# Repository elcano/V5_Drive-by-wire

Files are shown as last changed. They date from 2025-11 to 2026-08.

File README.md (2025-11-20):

# V5_Drive-by-wire
Updated code and PCB for light vehicle drive by wire.

This repository is for use with the **Drive by Wire** board created to be used for the ELCANO self-driving tricycle. It controls throttle (Ebike controller), brakes (solenoid) and steering (either linear servo or motor controller board with a linear actuator). All vehicle actions are logged to an SD card, which is the main data for debugging. Vehicle can be controlled by

1) 6-channel Radio Control (RC) unit

2) Operator controls (OP)

3) Vehicle automation computer via CAN. We have demonstrated a Jetson Nano using a Pixhawk to find GNSS points and move from waypoint to waypoint.

In order for this module to run external libraries are required.

Libraries needed are listed below:

Version 4 and 5 (Arduino Due)  _______________________________________________
* Due CAN and CAN Common by Collin Kidder
    https://github.com/collin80/due_can
    https://github.com/collin80/can_common

## To Install

* Download the **Drive_By_Wire** module into the project parent directory
```
git clone https://github.com/elcano/Drive-by-wire.git
```
* Move into the **Drive_By_Wire** folder
```
cd Drive_By_Wire
```
* Download the required libraries
```
git clone https://github.com/SweBarre/MCP48x2.git
git clone https://github.com/ivanseidel/DueTimer.git
git clone https://github.com/collin80/can_common.git
git clone https://github.com/collin80/due_can.git
```
* Add the folders above to the IDE directory. In Windows, add the required libraries to: C:\Users\<username>\Documents\Arduino\libraries
* Arduino Due requires additional installation. On the IDE, go to Tools -> Boards -> Boards Manager -> Arduino SAM Boards (32-bits ARM Cortex-M3) 

## Navigating Arduino IDE: 
* **Selecting Board:** Tools -> Board -> Arduino SAM Boards -> Arduino Due
* **Selecting Serial Port:** Tools -> Port -> COM (Arduino Due)
* **Accessing Serial Monitor:** Right-hand Corner -> Select Baud Rate (115200)

## Drive-by-Wire: 
* **Low-level board code with RC control support with existing code for brakes, steering, and throttle.**

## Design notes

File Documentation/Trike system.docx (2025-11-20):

# Trike system

High level organization is given in the block diagram

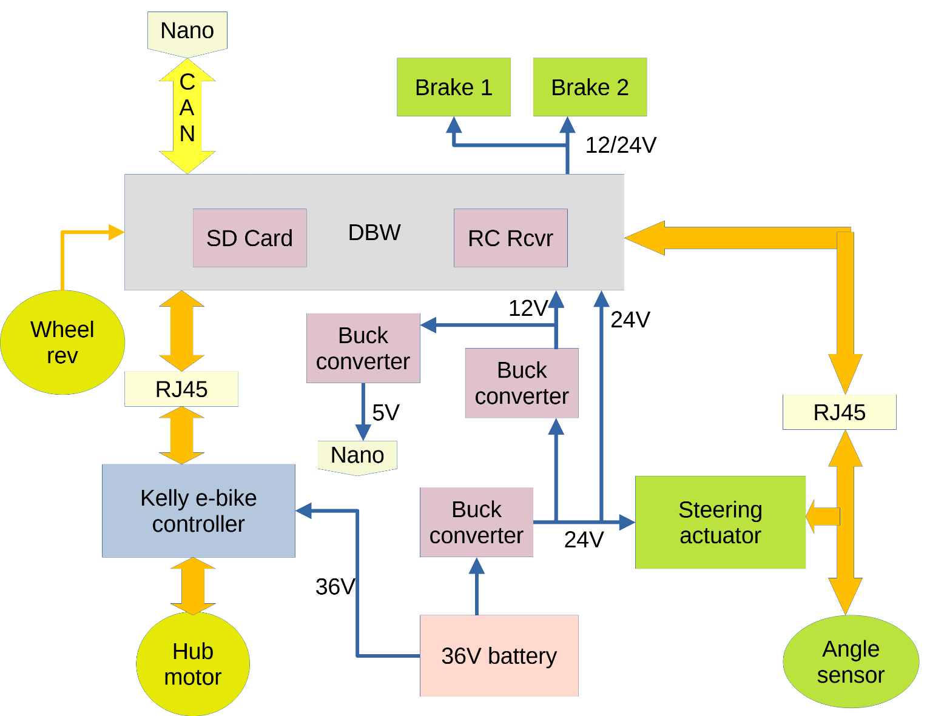
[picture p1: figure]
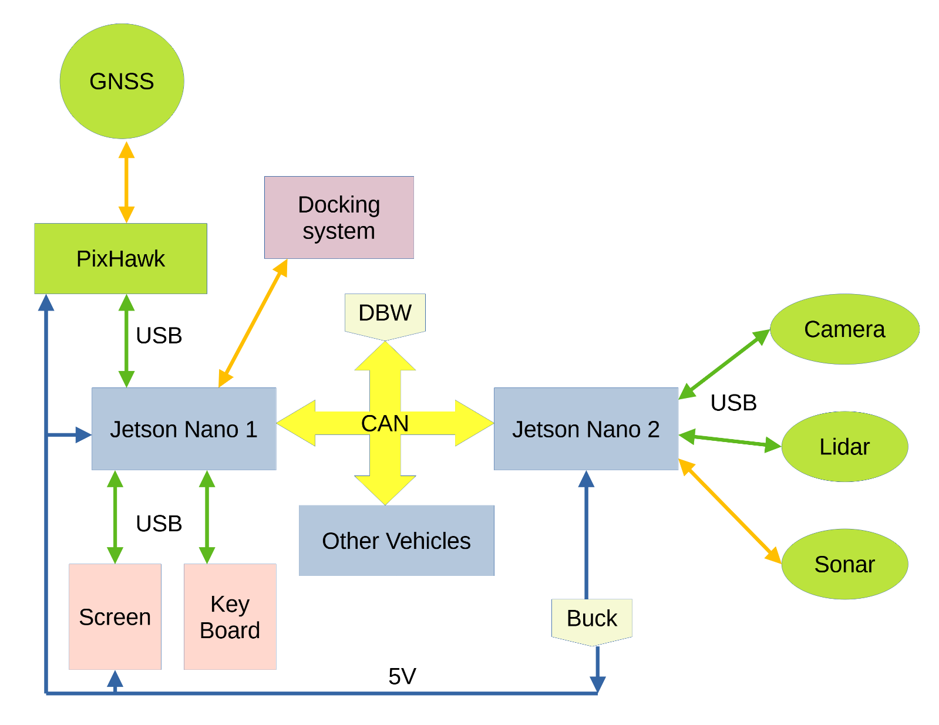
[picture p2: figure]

The steering system can be either a linear servo or a linear actuator with H-bridge. The present H-bridge system is not reliable, so the current version uses the servo. An angle sensor gives feedback on the wheel angle. The analog signal is subject to noise; it may be supplemented by a digital sensor. The servo can run on 12-24V. We use the 24V, supply, but it could also take 12V. The DBW board has a power outlet to the actuator for delaying its turn on. This signal should be jumpered to take either 12 or 24V.

Signals to the actuator and sensor are:

| Steering end | | DBW End
RJ45 Pin | V5A | V5B | V5A Pin (DUE) | V5B Pin (DUE)
1 | L_ANG | MISO | (A10) - in | MISO - in
2 | L_RTN | ANG CS | (A10) - in | D39 - out
3 | R_ANG | SCK | (A11) - in | SCK - in
4 | R_RTN | MOSI | (A11) – in | MOSI - out
5 | GND | GND | NC | NC
6 | PWM | R_TURN | D48 - out | D48 - out
7 | NC | L_TURN | D41 - out | D41 - out
8 | 5V | 5V | NC | NC

Ground and 5V for the angle sensors comes from the steering servo, not the Arduino. Signals in parenthesis require additional processing before going to the Due. The angle sensor pins subtract out the return signal. Throttle signals must be converted between 3.3 and 5 volts. Throttle control is handled by the Kelly e-bike controller. It must receive the 36V signal from the switch to turn on the controller. Its signals are:

RJ45 Pin | Signal | Due Pin | Kelly pin | Kelly wire color
1 | REV/FWD | (D36) | M12 | White
2 | Current meter | (A9) | F8 | Dark blue
3 | Brake | (DAC 1) | F2 | White
4 | BRK_SW (Regen) | (D43) | F13 | Brown
5 | Spare | (D24)
6 | Throttle | (DAC 0) | F3 | Dark green
7 | Speedometer | (D22) | 17 Hall B | Green
8 | EBIKE alive | (D45) | F4 or M11 | Purple or Dark grey
| 36V | | M7 | Pink

Speed is computed from a reed switch that produces an interrupt once per wheel revolution. A more accurate speed could be obtained from the Hall Phase signal with several pulses per revolution. This system has not been implemented. A third possibility would be a sensor on the axle that measures shaft rotation speed.

The trike can operate as a remote-control vehicle, via the RC unit. It can operate autonomously from a command from the Jetson Nano giving the speed and steering angle to reach the next waypoint. For computing paths, turn radius may be easier to implement than using wheel angle directly. A path segment can be specified by the reciprocal of the turning angle and the distance to travel on the segment. Going straight has an infinite turn angle; the reciprocal is 0. The Jetson Nano will need to take the route between waypoints and convert it into straight segments and circular arcs. The DBW software will have the task of setting the wheel angle to match a desired turn radius.

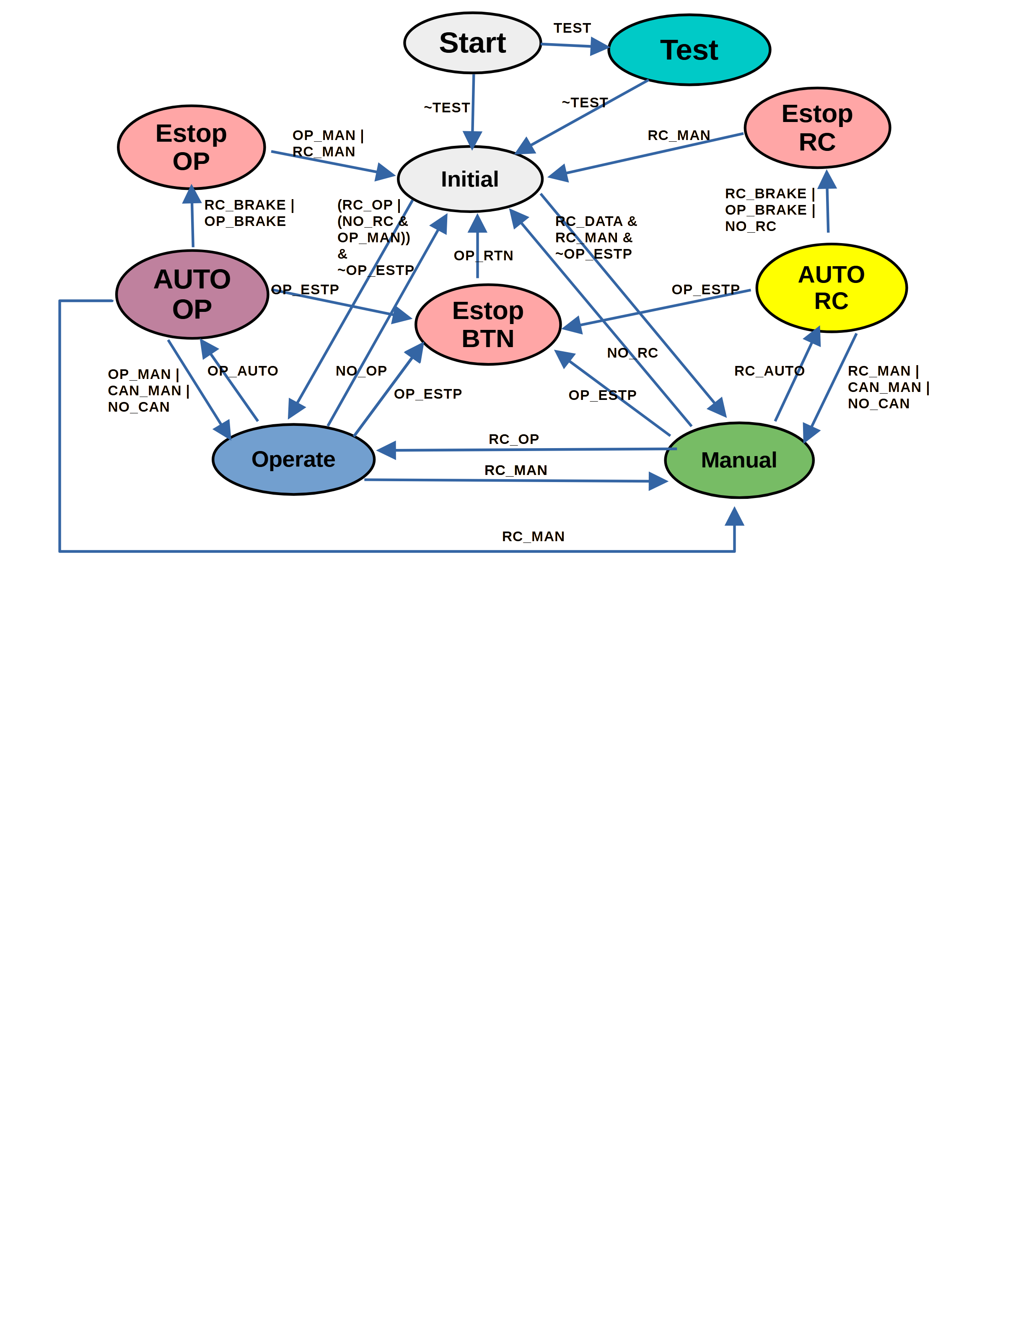
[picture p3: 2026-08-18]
Documentation/State transitions3.png

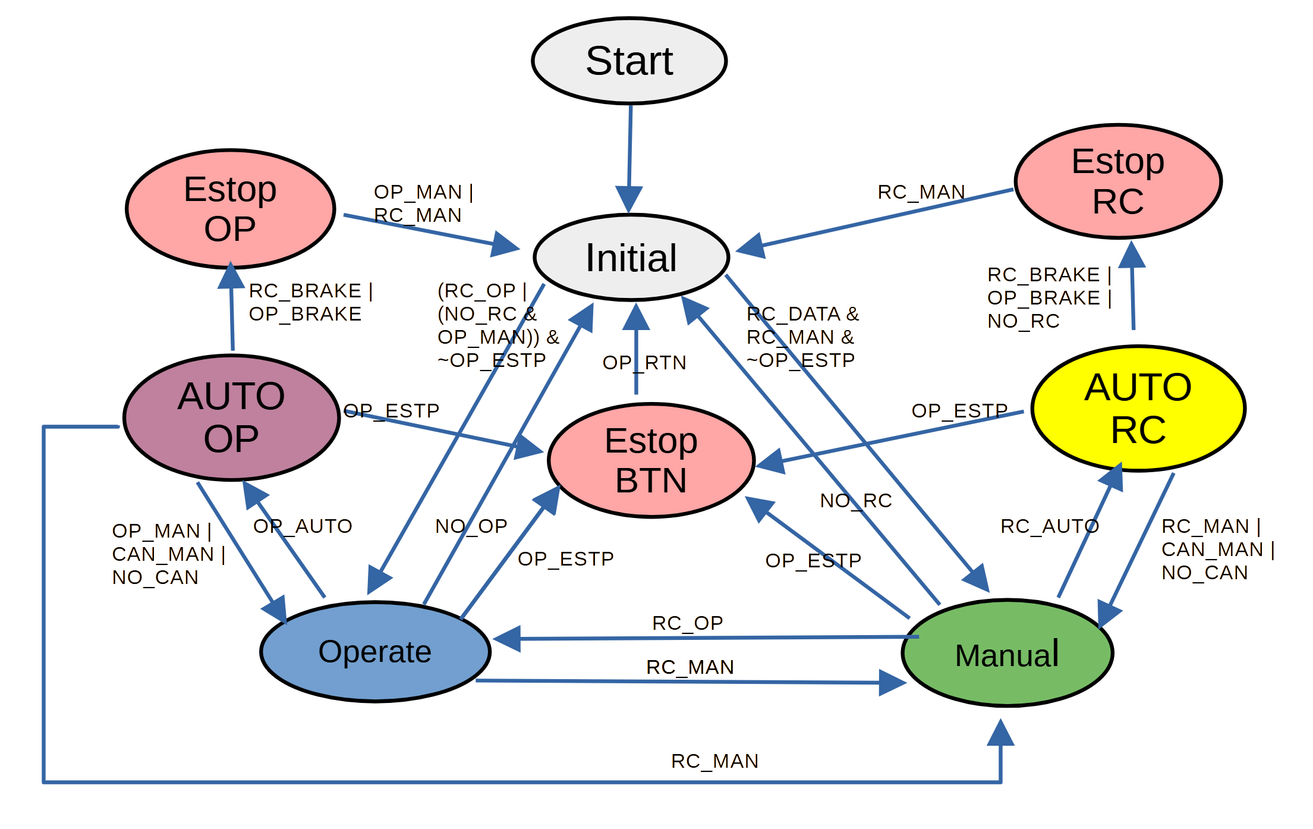
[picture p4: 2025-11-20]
Documentation/State transitions.png

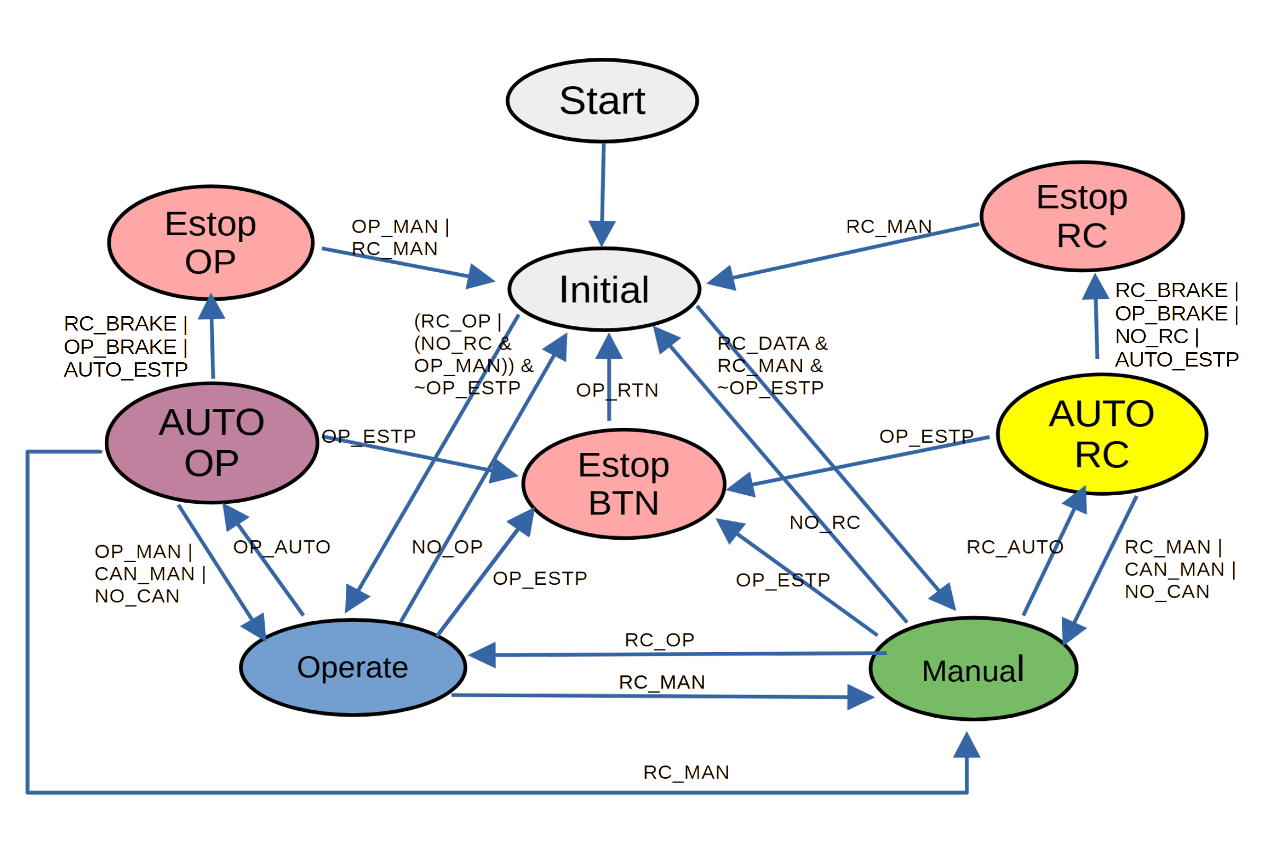
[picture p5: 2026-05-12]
Documentation/State transitions2.png

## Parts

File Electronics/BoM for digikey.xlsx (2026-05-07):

 |  |  |  |  |  |  |  | Components need to buy
Qty | unit price | board price | 10 board | On Hand | Need | Total | Device Name | Value | Notes | Digikey Part Number | Package | Part Label | Description | DESCRIPTION | External Link
1 | 0.1 | 0.1 | $1.00 | 0 | 10 | $1.00 | Capcitors | 47uF |  | 732-8823-1-ND | 5x125 mm case 2mm pitch | C16 | Aluminum Electrolytic Capacitors | 47 µF 25 V Aluminum Electrolytic Capacitors Radial, Can 2000 Hrs @ 105°C | https://www.digikey.com/en/products/detail/w%C3%BCrth-elektronik/860020472006/5727060
~~1~~ | ~~0.118~~ | ~~0.118~~ | ~~$1.18~~ | ~~0~~ | 0 | $0.00 | ~~Capcitors~~ | ~~47uF~~ | 0 in stock | ~~399-ESS476M025AE2EACT-ND~~ | ~~5x7 mm case 2mm pitch~~ | ~~C16~~ | ~~Aluminum Electrolytic Capacitors~~ | ~~47 µF 25 V Aluminum Electrolytic Capacitors Radial, Can 1000 Hrs @ 105°C~~ | ~~https://www.digikey.com/en/products/detail/kemet/ess476m025ae2ea/13176268~~
3 | 0.055 | 0.165 | $1.65 | 0 | 30 | $1.65 | Diode |  |  | 1N4148FSCT-ND | Cut Tape (CT) | D11,D12,D13 | DIODE STANDARD 100V 200MA DO35 | Diode 100 V 200mA Through Hole DO-35 | https://www.digikey.com/en/products/detail/onsemi/1N4148TR/458811?s=N4IgTCBcDaIIwDkAsckA4BiBlAwgFQFoEAREAXQF8g
3 | 0.088 | 0.264 | $2.64 | 0 | 30 | $2.64 | 2N3904 BJT |  |  | 4878-2N3904CT-ND |  | Q1,Q2,Q3 | BJT | Bipolar (BJT) Transistor NPN 40 V 200 mA 300MHz 625 mW Through Hole TO-92 | https://www.digikey.com/en/products/detail/diotec-semiconductor/2N3904/13164701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
2 | 0.23 | 0.46 | $4.60 | 0 | 20 | $4.60 | Test Points |  |  | 36-1033-ND |  | DAC0,GND1 | PC TEST POINT LOOP | PC Test Point, Loop Brass Tin Plating Through Hole Mounting Type | https://www.digikey.com/en/products/detail/keystone-electronics/1033/315149
1 | 0.214 | 0.214 | $2.14 | 0 | 10 | $2.14 | Switch |  |  | CKN9092-ND |  | SW1 | SWITCH TACTILE SPST-NO 0.05A 12V | Tactile Switch SPST-NO Top Actuated Through Hole | https://www.digikey.com/en/products/detail/c-k/PTS645SL50-2-LFS/1146781?s=N4IgTCBcDaIMIGkByBOADCsBaJAREAugL5A
1 | 3.19 | 3.19 | $31.90 | 0 | 10 | $31.90 | R-78E5.0-0.5 |  |  | 945-1648-5-ND | 11.6x8.5x10.4 2.54 pitch | U6 | Voltage regulator --5V | Linear Regulator Replacement DC DC Converter 1 Output 5V 500mA 7V - 28V Input | https://www.digikey.com/en/products/detail/recom-power/R-78E5-0-0-5/2834904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
3 | 0.659 | 1.977 | $19.77 | 10 | 20 | $13.18 | RJ_45 |  |  | 609-1046-ND | 15.3x17.74x12.7 | J1,J2,J3 | Modular/Ethernet Connector (RJ45) Jack | in stock, | https://www.digikey.com/en/products/detail/amphenol-cs-fci/54602-908LF/1001360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
3 | 0.353 | 1.059 | $10.59 | 24 | 6 | $2.12 | Pinheader-1x6 |  |  | S7004-ND |  | J4,J5,J6 | Pin connector(female) |  | https://www.digikey.com/en/products/detail/sullins-connector-solutions/PPTC061LFBN-RC/810145
1 | 0.321 | 0.321 | $3.21 | 10 | 0 | $0.00 | Pinheader-1x4 |  |  | S7037-ND |  | J7 | Pin connector(female) |  | https://www.digikey.com/en/products/detail/sullins-connector-solutions/PPPC041LFBN-RC/810176
1 | 0.435 | 0.435 | $4.35 | 10 | 0 | $0.00 | Pinheader-1x8 |  |  | S7006-ND |  | J8 | Pin connector(female) |  | https://www.digikey.com/en/products/detail/sullins-connector-solutions/PPTC081LFBN-RC/810147
 |  |  |  |  | 200 | $5.84 | Pins for socket | 500798000 |  | WM1142CT-ND | Molex |  | CONN SOCKET 26-28AWG CRIMP TIN | Socket Contact Tin 26-28 AWG Crimp
1 | 0.197 | 0.197 | $1.97 | 0 | 10 | $1.97 | Female connector - 1x6 | 510210600 |  | WM1724-ND | Molex
2 | 0.062 | 0.124 | $1.24 | 0 | 20 | $1.24 | Female connector - 1x4 | 10155244-04111lf |  | 609-10155244-04111LF-ND | Amphenol
1 | 0.689 | 0.689 | $6.89 | 0 | 10 | $6.89 | Male pinheader - 1x6 | 532610671 |  | WM7624CT-ND | Molex | J9 | CONN HEADER SMD R/A 6POS 1.25MM | Connector Header Surface Mount, Right Angle 6 position 0.049" (1.25mm)
~~1~~ | ~~0.426~~ | ~~0.426~~ | ~~$4.26~~ | ~~0~~ | ~~0~~ | ~~$0.00~~ | ~~Male pinheader - 1x6~~ | ~~10114830-10106LF~~ |  | ~~609-6042-1-ND~~ | ~~Amphenol~~ | ~~J9~~ | ~~CONN HEADER SMD R/A 6POS 1.25MM~~ | ~~Connector Header Surface Mount, Right Angle 6 position 0.049" (1.25mm)~~
2 | 0.242 | 0.484 | $4.84 | 0 | 20 | $4.84 | Male pinheader - 1x4 | 10155242-04111LF |  | 609-10155242-04111LFCT-ND | Amphenol | J10,J11 | WF 1.25MM 90 HF LCP-10155242-041 | Connector Header Surface Mount, Right Angle 4 position 0.049" (1.25mm)
1 | 0.416 | 0.416 | $4.16 | 0 | 10 | $4.16 | JST Pinheader-1x6 | SM06B-GHS-TB |  | 455-1568-1-ND | Back order | J9 | CONN HEADER SMD R/A 6POS 1.25MM | Connector Header Surface Mount, Right Angle 6 position 0.049" (1.25mm) | https://www.digikey.com/en/products/detail/jst-sales-america-inc/SM06B-GHS-TB/807790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
2 | 0.33 | 0.66 | $6.60 | 0 | 20 | $6.60 | JST Pinheader-1x4 | SM04B-GHS-TB |  | 455-1566-1-ND | Back order | J10,J11 | CONN HEADER SMD R/A 4POS 1.25MM | Connector Header Surface Mount, Right Angle 4 position 0.049" (1.25mm) | https://www.digikey.com/en/products/detail/jst-sales-america-inc/SM04B-GHS-TB/807788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
5 | 0.49 | 2.45 | $24.50 | 5 | 0 | $0.00 | ~~Stacking Pinheader-1x8~~ |  |  | ~~HDR100IMP08F-G-V-ST~~ |  | ~~J14,J15,J16,J18,J19~~ | ~~0.1" 8 PIN VERTICAL FEMALE STACK~~ | ~~8 Position Header Connector 0.100" (2.54mm) Through Hole Gold~~
1 | 1 | 1 | $10.00 | 4 | 0 | $0.00 | ~~Stacking Pinheader-1x10~~ | ~~Include 6~~ |  | ~~920-0087-01~~ |  | ~~J17~~ | ~~CONN HDR 10POS 0.1 GLD PCB 1=6PC~~ | ~~10 Position Header Connector 0.100" (2.54mm) Through Hole Gold~~
1 | 0.49 | 0.49 | $4.90 | 0 | 0 | $0.00 | ~~Stacking Pinheader-2x18~~ | ~~Uses 2 1x8 and 2 1x10~~ |  | ~~HDR100IMP08F-G-V-ST & 920-0087-01~~ |  | ~~J20~~ | ~~using two 1x8 and two 1x10~~ | ~~The price here is for the 1x8 version. For the 1x10 version, it already includes more components, so there is no need to buy anything extra.~~
 |  |  |  | 25 |  |  | ~~Stacking pinheade 1x6~~
1 | 0.49 | 0.49 | $4.90 | 20 | 0 | $0.00 | ~~Stacking Pinheader-2x3~~ |  |  | ~~S7106-ND~~ |  | ~~J21~~ | ~~CONN HDR 6POS 0.1 GOLD PCB~~ | ~~6 Position Header Connector 0.100" (2.54mm) Through Hole Gold~~
2 | 5.95 | 11.9 | $11.90 |  | 2 | $11.90 | Stacking pinheader set | 5-1x36 |  | 3366 |  | J20,J16,J18,J19 |  |  | https://www.adafruit.com/product/3366
1 | 1.76 | 1.76 | $17.60 | 0 | 10 | $17.60 | Stacking Pinheader set | 1-2x3,2-1x6,2-1x8,1-1x10 |  | 85 |  | J21,J17,J14,J15 |  |  | https://www.adafruit.com/product/85
1 | 0.745 | 0.745 | $7.45 | 0 | 10 | $7.45 | Jack DC power |  |  | 839-54-00129-ND |  | J22 | Jack DC power supply | Power Barrel Connector Jack 2.10mm ID (0.083"), 5.50mm OD (0.217") Through Hole, Right Angle | https://www.digikey.com/en/products/detail/tensility-international-corp/54-00129/9685438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
4 | 0.12 | 0.48 | $4.80 | 40 | 0 | $0.00 | Jumper pins |  |  | 732-5316-ND |  | JP5,JP6,JP7,JP8 | Jumpers using Connector Header | Connector Header Through Hole 3 position 0.100" (2.54mm)
 | 0.0237 |  |  |  | 100 | $2.37 | Jumper shunts |  |  | S9337-ND |  |  |  |  | https://www.digikey.com/en/products/detail/sullins-connector-solutions/QPC02SXGN-RC/2618262
2 | 1.22 | 2.44 | $24.40 | 2 | 18 | $21.96 | Screw-terminal-1x5 | 14-26 AWG |  | TB0012-508-05GR |  | J12,J13 | Screw terminal | TERM BLK 5POS 180DEG 5.08MM PCB, Max current is 12A,V 300V | https://www.digikey.com/en/products/detail/same-sky-formerly-cui-devices/TB0012-508-05GR/26490319
~~2~~ | ~~1.382~~ | ~~2.764~~ | ~~$27.64~~ | ~~0~~ | ~~20~~ | ~~$0.00~~ | ~~Screw-terminal-1x5~~ | 16-30 AWG |  | 2861-ELK508V-05P-ND |  | ~~J12,J13~~ | ~~Screw terminal~~ | ~~TERM BLK 5POS 180DEG 5.08MM PCB, Max current is 13.5A,V 300V~~ | ~~https://www.digikey.com/en/products/detail/dinkle-corporation-usa/ELK508V-05P/17677381
3 | 0.9584 | 2.8752 | $28.75 | 0 | 25 | $23.96 | Relay |  |  | 2449-J107F1CS125VDC.36-ND | 19x15x15.5 | K1,K2,K3 | RELAY GEN PURPOSE SPDT 12A 5V | General Purpose Relay SPDT (1 Form C) 5VDC Coil Through Hole | https://www.digikey.com/en/products/detail/cit-relay-and-switch/J107F1CS125VDC-36/14002162
 | 2.33 |  |  | 5 |  |  | Relay |  |  | ORWH-SH-105D1F,000 | 19x15x15.5 | K1,K2,K3 | RELAY GEN PURPOSE SPDT 15A 5V | General Purpose Relay SPDT (1 Form C) 5VDC Coil Through Hole
1 | 7.5 | 7.5 | $60.00 | 4 | 4 | $30.00 | Real time clock |  |  | 3296
1 | 7.5 | 7.5 | $60.00 | 4 | 4 | $30.00 | SD card board |  |  | 254
1 | 0.95 | 0.95 |  | 6 | 6 | $5.70 | Clock battery | CR1220 |  | 380
 |  | 54.5432 | 398.832 |  |  | $240.71
 |  | Base | Shipping | Tax | Tariff
 | 2026-05-05 |  | 18.58 | 8.21 |  | $86.04 | Adafruit | 254 out of stock
 | 2026-05-05 | 134.5 | 6.99 | 16.15 | 11.55 | 169.19 | DigiKey | JST out of stock
 | 2026-05-05 | 20.99 | 4 | 2.81 | 0.63 | 29.42 | DigiKey | Substitute connectors
 |  |  |  |  |  | $284.65

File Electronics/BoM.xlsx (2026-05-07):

 |  |  |  | Board Manufacturer Specs
 |  |  | Traces are 15 mil | Board needs 2 oz copper |  | Two Layers: Front & Back
 |  |  |  | Main Through hole components
Qty | unit price | Total price | Device Name | Value | In BoM? | Digikey Part Number | Package | Part Label | Description | DESCRIPTION | External Link | DIGI-KEY_PURCHASE_URL | MANUFACTURER_PART_NUMBER | MF | MP | MPN | OC_FARNELL | OC_NEWARK | PACKAGE | PROD_ID | SF_SKU | SPICEPREFIX | VALUE | VENDOR
8 | 0.007(for buying 10) | 0.07 | R_0603_1208 | 22k ohms | yes | 311-22.0KHRCT-ND | Cut Tape (CT) | R10,R11,R13,R12,R14,R15,R16,R17 | Chip Resistor | in stock, 1% tolerance,(1.60mm x 0.80mm)
10 | 0.006 | 0.06 | R_0603_1208 | 10k ohms | yes | 311-10.0KHRCT-ND | Cut Tape (CT) | R1,R2,R3,R22,R23,R25,R29,R30,R34,R43 | Chip Resistor | in stock, 1% tolerance,(1.60mm x 0.80mm)
2 | 0.007（for buying 10) | 0.07 | R_0603_1208 | 22 ohms | yes | 311-22.0HRCT-ND | Cut Tape (CT) | R32,R33 | Chip Resistor | in stock, 1% tolerance,(1.60mm x 0.80mm)
10 | 0.008 | 0.08 | R_0603_1208 | 1k ohms | yes | 311-1.00KHRCT-ND | Cut Tape (CT) | R18,R19,R24,R35,R36,R37,R38,R39,R40,R41 | Chip Resistor | in stock, 1% tolerance,(1.60mm x 0.80mm)
3 | 0.008(for buying 10) | 0.08 | R_0603_1208 | 150 ohms | yes | 311-150HRCT-ND | Cut Tape (CT) | R26,R27,R28 | Chip Resistor | in stock, 1% tolerance,(1.60mm x 0.80mm)
1 | 0.1 | 0.1 | R_0603_1208 | 2.7k ohms | yes | 311-2.70KHRCT-ND | Cut Tape (CT) | R5 | Chip Resistor | in stock, 1% tolerance,(1.60mm x 0.80mm)
1 | 0.1 | 0.1 | R_0603_1208 | 1.5k ohms | yes | 13-RC0603FR-101K5LCT-ND | Cut Tape (CT) | R4 | Chip Resistor | in stock, 1% tolerance,(1.60mm x 0.80mm)
1 | 0.1 | 0.1 | R_0603_1208 | 120 ohms | yes | 311-120HRCT-ND | Cut Tape (CT) | R31 | Chip Resistor | in stock, 1% tolerance,(1.60mm x 0.80mm)
2 | 0.006(for buying 10) | 0.06 | R_0603_1208 | 15k ohms | yes | RMCF0603FG15K0CT-ND | Cut Tape (CT),RMCF | R6,R8 | Chip Resistor | in stock, 1% tolerance,(1.55mm x 0.80mm)
2 | 0.009(for buying10) | 0.09 | R_0603_1208 | 27k ohms | yes | 13-RC0603FR-1327KLCT-ND | Cut Tape (CT) | R7,R9 | Chip Resistor | in stock, 1% tolerance,(1.60mm x 0.80mm)
2 | 0.007(for buying 10) | 0.07 | R_0603_1208 | 4.7k ohms | yes | 311-4.70KHRCT-ND | Cut Tape (CT) | R20,R21 | Chip Resistor | in stock, 1% tolerance,(1.60mm x 0.80mm)
1 | 0.1 | 0.1 | R_0603_1208 | 100 ohms | yes | 311-100HRCT-ND | Cut Tape (CT) | R42 | Chip Resistor | in stock, 1% tolerance,(1.60mm x 0.80mm)
3 | 0.71 | 2.13 | RJ_45 |  | yes | 609-1046-ND | Modular/Ethernet Connector (RJ45, RJ11) Jacks | J1,J2,J3 | RJ45 | in stock,
3 | 0.42 | 1.26 | Pinheader-1x6 |  | yes | S7004-ND |  | J4,J5,J6 | Pin connector(female) | IC REG LINEAR 3.3V 1A DPAK
1 | 0.38 | 0.38 | Pinheader-1x4 |  | yes | S7037-ND |  | J7 | Pin connector(female)
1 | 0.51 | 0.51 | Pinheader-1x8 |  | yes | S7006-ND |  | J8 | Pin connector(female)
1 | 0.48 | 0.48 | JST Pinheader-1x6 |  | yes | 455-1568-1-ND |  | J9 | CONN HEADER SMD R/A 6POS 1.25MM | Connector Header Surface Mount, Right Angle 6 position 0.049" (1.25mm)
2 | 0.38 | 0.76 | JST Pinheader-1x4 |  | yes | 455-1566-1-ND |  | J10,J11 | CONN HEADER SMD R/A 4POS 1.25MM | Connector Header Surface Mount, Right Angle 4 position 0.049" (1.25mm)
2 | 1.84 | 3.68 | Screw-terminal-1x5 |  | yes | 2861-ELK508V-05P-ND |  | J12,J13 | Screw terminal | TERM BLK 5POS 180DEG 5.08MM PCB, Max current is 13.5A,V 300V
5 | 0.49 | 2.45 | Stacking Pinheader-1x8 |  | yes | HDR100IMP08F-G-V-ST |  | J14,J15,J16,J18,J19 | 0.1" 8 PIN VERTICAL FEMALE STACK | 8 Position Header Connector 0.100" (2.54mm) Through Hole Gold
1 | 5(include 6) | 5 | Stacking Pinheader-1x10 |  | yes | 920-0087-01 |  | J17 | CONN HDR 10POS 0.1 GLD PCB 1=6PC | 10 Position Header Connector 0.100" (2.54mm) Through Hole Gold
1 | 0.49 | 0.98 | Stacking Pinheader-2x18 | Uses 2 1x8 and 2 1x10 | yes | HDR100IMP08F-G-V-ST & 920-0087-01 |  | J20 | using two 1x8 and two 1x10 | The price here is for the 1x8 version. For the 1x10 version, it already includes more components, so there is no need to buy anything extra.
1 | 0.49 | 0.49 | Stacking Pinheader-2x3 |  | yes | S7106-ND |  | J21 | CONN HDR 6POS 0.1 GOLD PCB | 6 Position Header Connector 0.100" (2.54mm) Through Hole Gold
1 | 0.91 | 0.91 | Jack DC power |  | yes | 839-54-00129-ND |  | J22 | Jack DC power supply | Power Barrel Connector Jack 2.10mm ID (0.083"), 5.50mm OD (0.217") Through Hole, Right Angle
4 | 0.12 | 0.48 | Jumpers |  | yes | 732-5316-ND |  | JP5,JP6,JP7,JP8 | Jumpers using Connector Header | Connector Header Through Hole 3 position 0.100" (2.54mm)
 |  |  |  | Capcitors
Qty |  |  | Device Name | Value | In BoM? | Digikey Part Number | Package | Part Label | Description | DESCRIPTION | External Link | DIGI-KEY_PURCHASE_URL | MANUFACTURER_PART_NUMBER | MF | MP | MPN | OC_FARNELL | OC_NEWARK | PACKAGE | PROD_ID | SF_SKU | SPICEPREFIX | VALUE | VENDOR
8 | 0.011(buying for 10) | 0.11 | Capcitors | 0.1uF | yes | 399-C0603C104K5RACTUCT-ND |  | C1,C2,C3,C4,C5,C6,C7,C10 | CAP CER 0.1UF 50V X7R 0603 | 0.1 µF ±10% 50V Ceramic Capacitor X7R 0603 (1608 Metric)
2 | 0.1 | 0.2 | Capcitors | 100pF | yes | 399-C0603C101K5RACTUCT-ND |  | C8,C9 | CAP CER 100PF 50V X7R 0603 | 100 pF ±10% 50V Ceramic Capacitor X7R 0603 (1608 Metric)
2 |  |  | Capcitors | 1uF | yes | 399-C0603C105K4RACTUCT-ND |  | C13,C14 | CAP CER 1UF 16V X7R 0603 | 1 µF ±10% 16V Ceramic Capacitor X7R 0603 (1608 Metric)
1 |  |  | Capcitors | 10uF | yes |  |  | C11,C12 | CAP CER 2.2UF 50V X5R 0603 | 2.2 µF ±10% 50V Ceramic Capacitor X5R 0603 (1608 Metric)
 |  |  | Capcitors |  | yes | 478-8875-1-ND |  | C13,C14 | Capacitor polarized | 10 µF Molded Tantalum Capacitors 16 V 1206 (3216 Metric) 3Ohm
1 | 0.19 | 0.19 | Capcitors | 47uF | yes | 399-ESS476M025AE2EACT-ND |  | C16 | Aluminum Electrolytic Capacitors | 47 µF 25 V Aluminum Electrolytic Capacitors Radial, Can 1000 Hrs @ 105°C
 |  |  |  | Other Components
Qty |  |  | Device Name | Value | In BoM? | Digikey Part Number | Package | Part Label | Description | DESCRIPTION | External Link | DIGI-KEY_PURCHASE_URL | MANUFACTURER_PART_NUMBER | MF | MP | MPN | OC_FARNELL | OC_NEWARK | PACKAGE | PROD_ID | SF_SKU | SPICEPREFIX | VALUE | VENDOR
2 | 0.46 | 0.92 | LM358D |  | yes | 497-18378-ND |  | U1,U2 | LM358D | Standard (General Purpose) Amplifier 2 Circuit 8-SOIC
1 | 3.19 | 3.19 | TCAN334G |  | yes | 296-49940-1-ND | Cut Tape (CT) | U3 | TCAN334G | 1/1 Transceiver CANbus 8-SOIC
1 | 1.82 | 1.82 | TXB0108PWR |  | yes | 296-21527-1-ND | Cut Tape (CT) | U4 | Level shifter 5--3.3V | Voltage Level Translator Bidirectional 1 Circuit 8 Channel 100Mbps 20-TSSOP
1 | 0.52 | 0.52 | NCP1117 |  | yes | NCP1117DT33T5GOSCT-ND |  | U5 | Voltage regulator 5--3.3V | Linear Voltage Regulator IC Positive Fixed 1 Output 1A DPAK
1 | 0.54 | 0.54 | LP2985 |  | yes | 296-26128-1-ND |  | U6 | Voltage regulator --5V | Linear Voltage Regulator IC Positive Fixed 1 Output 150mA SOT-23-5
3 | 0.14 | 0.42 | 2N3904 |  | yes | 4878-2N3904CT-ND |  | Q1,Q2,Q3 | BJT | Bipolar (BJT) Transistor NPN 40 V 200 mA 300MHz 625 mW Through Hole TO-92
3 | 0.15 | 0.45 | LED |  | yes | 475-LGR971-KN-1CT-ND |  | D1,D2,D3 | LED light for relays | LED GREEN DIFFUSED 0805 SMD
1 | 0.15 | 0.15 | LED |  | yes | 475-LSR976-NR-1CT-ND |  | D4 | LED light for power | LED RED DIFFUSED 0805 SMD
1 | 0.15 | 0.15 | LED |  | yes | 475-LYR976-PS-36-0-20-R18CT-ND |  | D6 | LED light for debug | LED YELLOW DIFFUSED 0805 SMD
1 | 0.17 | 0.17 | NUP2105L |  | yes | 4878-NUP2105LCT-ND |  | D5 | TVS DIODE 24VWM 44VC SOT233 | 44V Clamp 8A (8/20µs) Ipp Tvs Diode Surface Mount SOT-23-3 (TO-236)
1 | 0.2 | 0.2 | D-Schottky |  | yes | B140-FDICT-ND |  | D7 | DIODE SCHOTTKY 40V 1A SMA | DIODE SCHOTTKY 40V 1A SMA
3 | 0.1 | 0.3 | Diode |  | yes | 1N4148FSCT-ND | Cut Tape (CT) | D11,D12,D13 | DIODE STANDARD 100V 200MA DO35 | Diode 100 V 200mA Through Hole DO-35
1 | 0.24 | 0.24 | Switch |  | yes | CKN9092-ND |  | SW1 | SWITCH TACTILE SPST-NO 0.05A 12V | Tactile Switch SPST-NO Top Actuated Through Hole
3 | 1.11 | 3.33 | Relay |  | yes | 2449-J107F1CS125VDC.36-ND |  | K1,K2,K3 | RELAY GEN PURPOSE SPDT 12A 5V | General Purpose Relay SPDT (1 Form C) 5VDC Coil Through Hole
2 | 0.28 | 0.56 | Test Points |  | yes | 36-1033-ND |  | DAC0,GND1 | PC TEST POINT LOOP | PC Test Point, Loop Brass Tin Plating Through Hole Mounting Type
 | total price: | 34.9

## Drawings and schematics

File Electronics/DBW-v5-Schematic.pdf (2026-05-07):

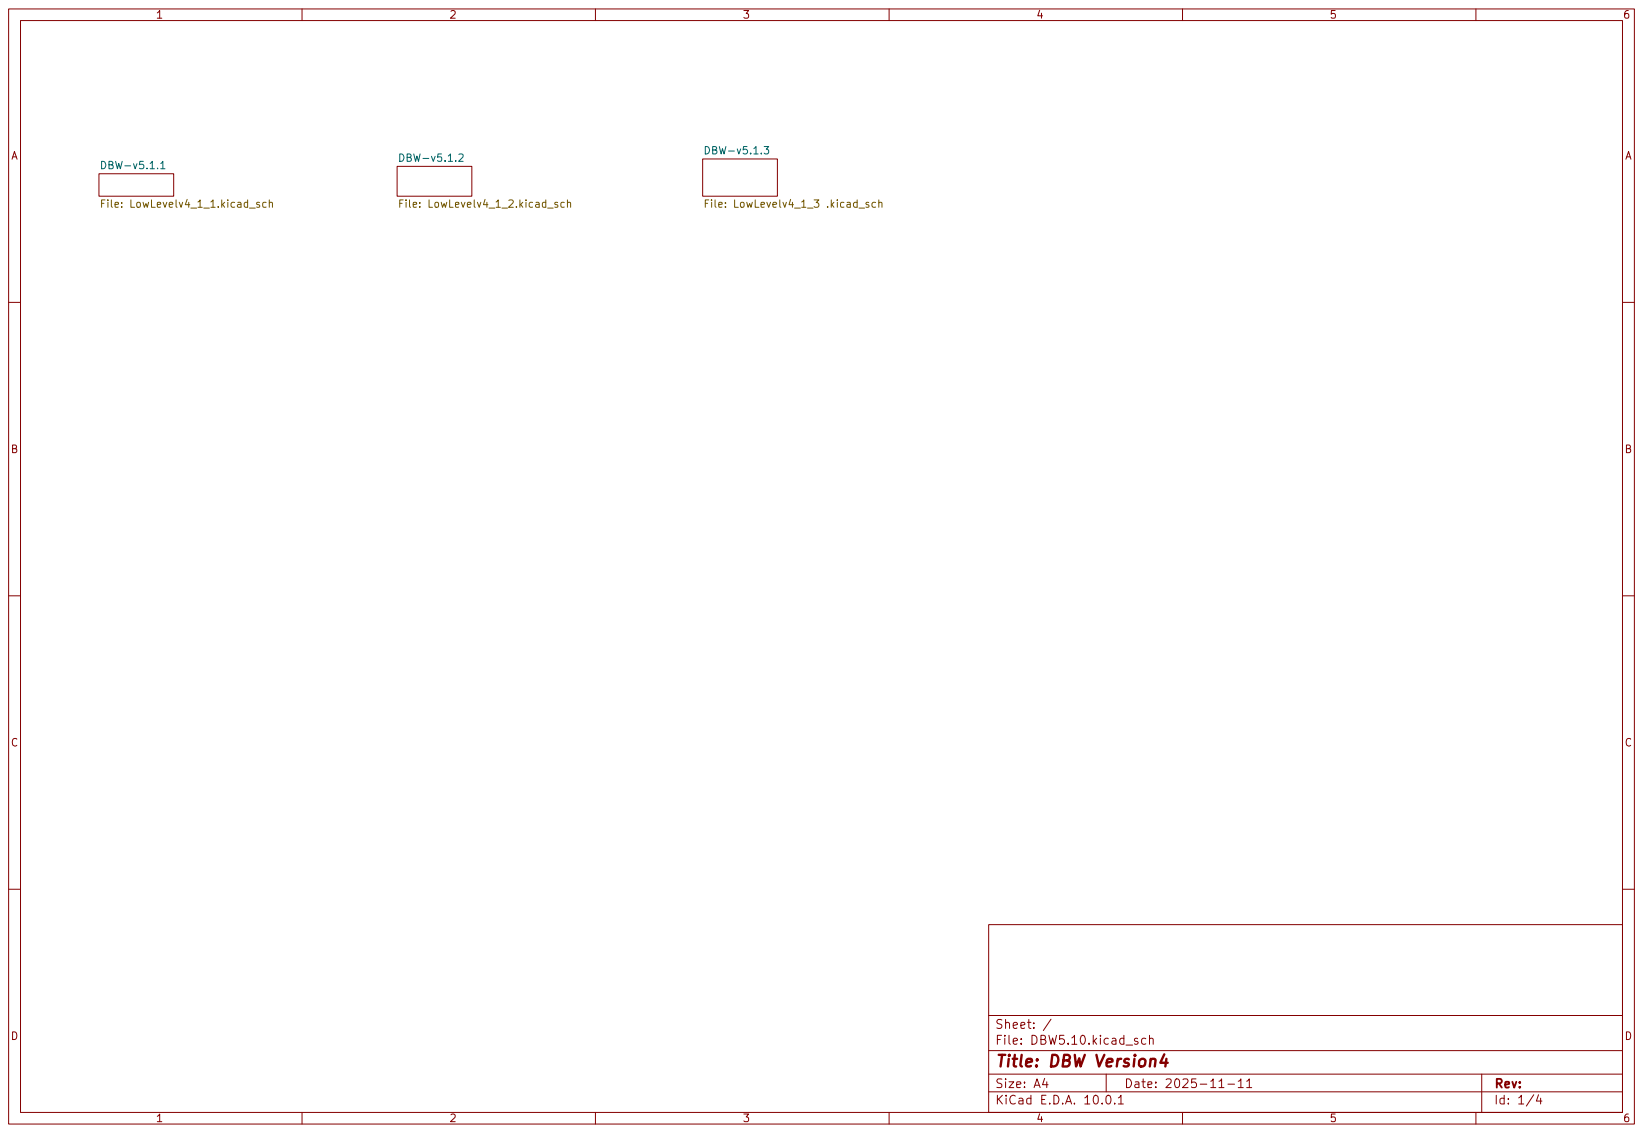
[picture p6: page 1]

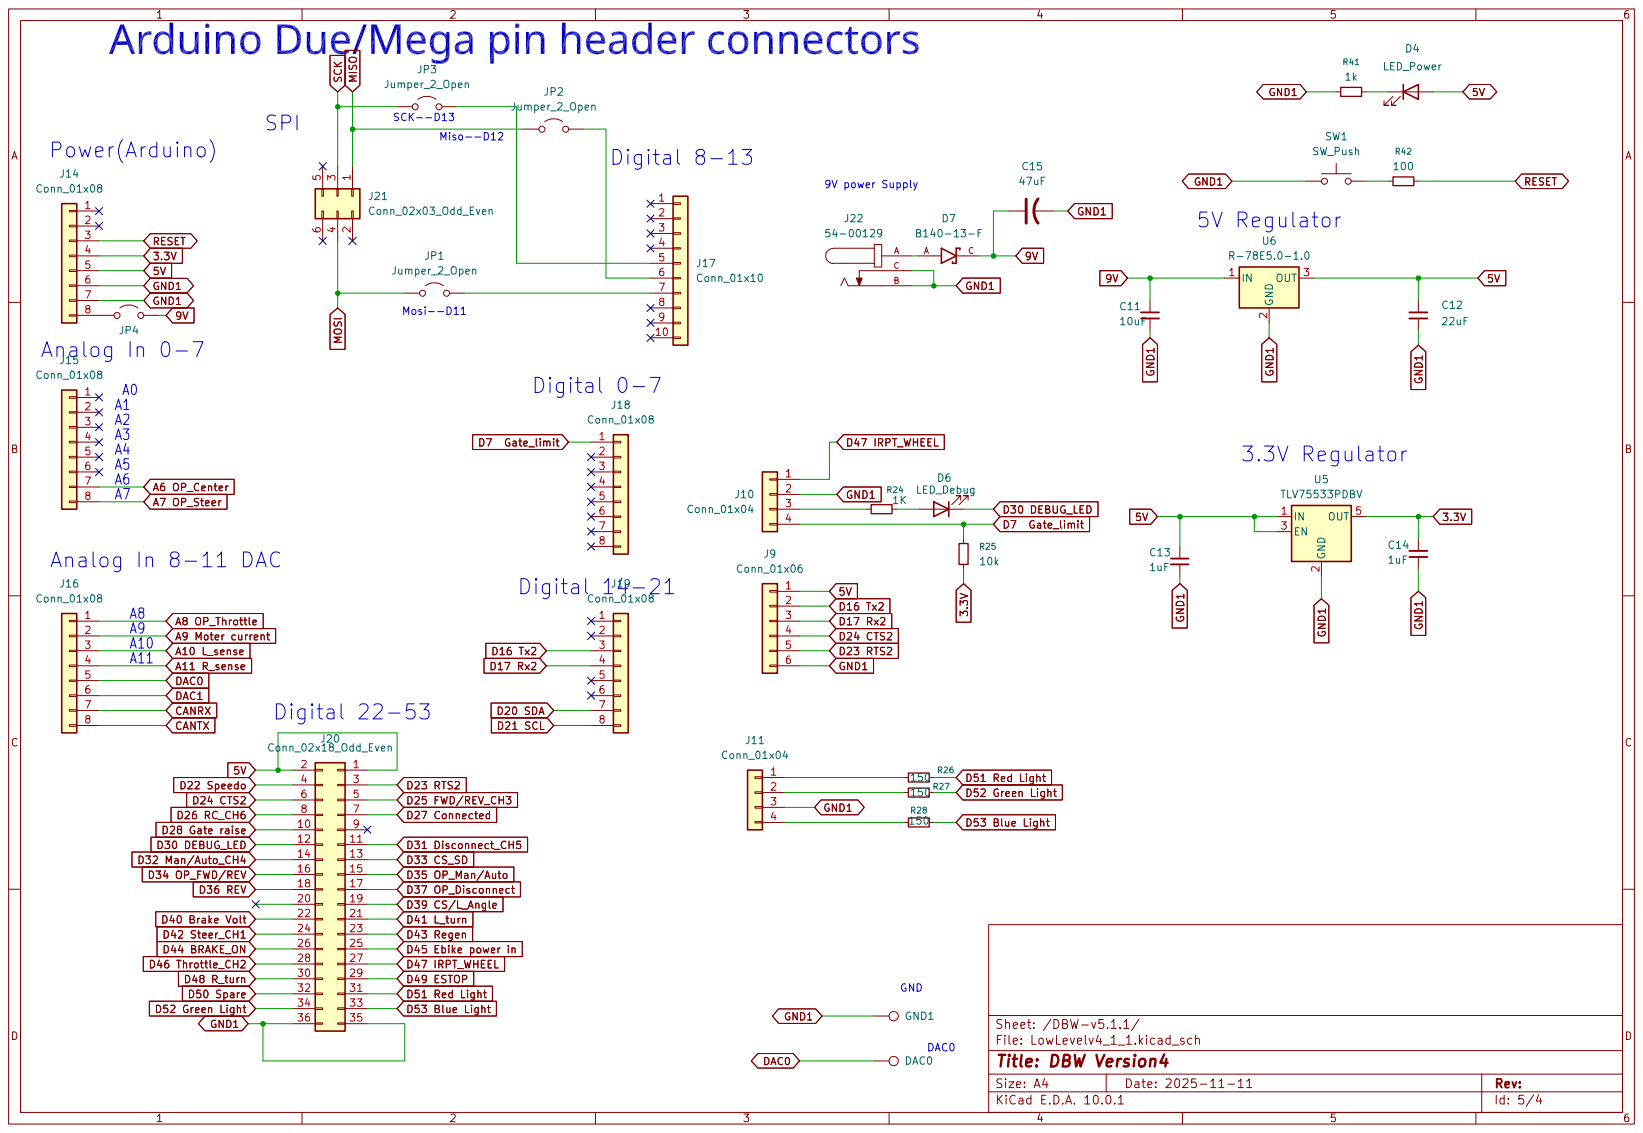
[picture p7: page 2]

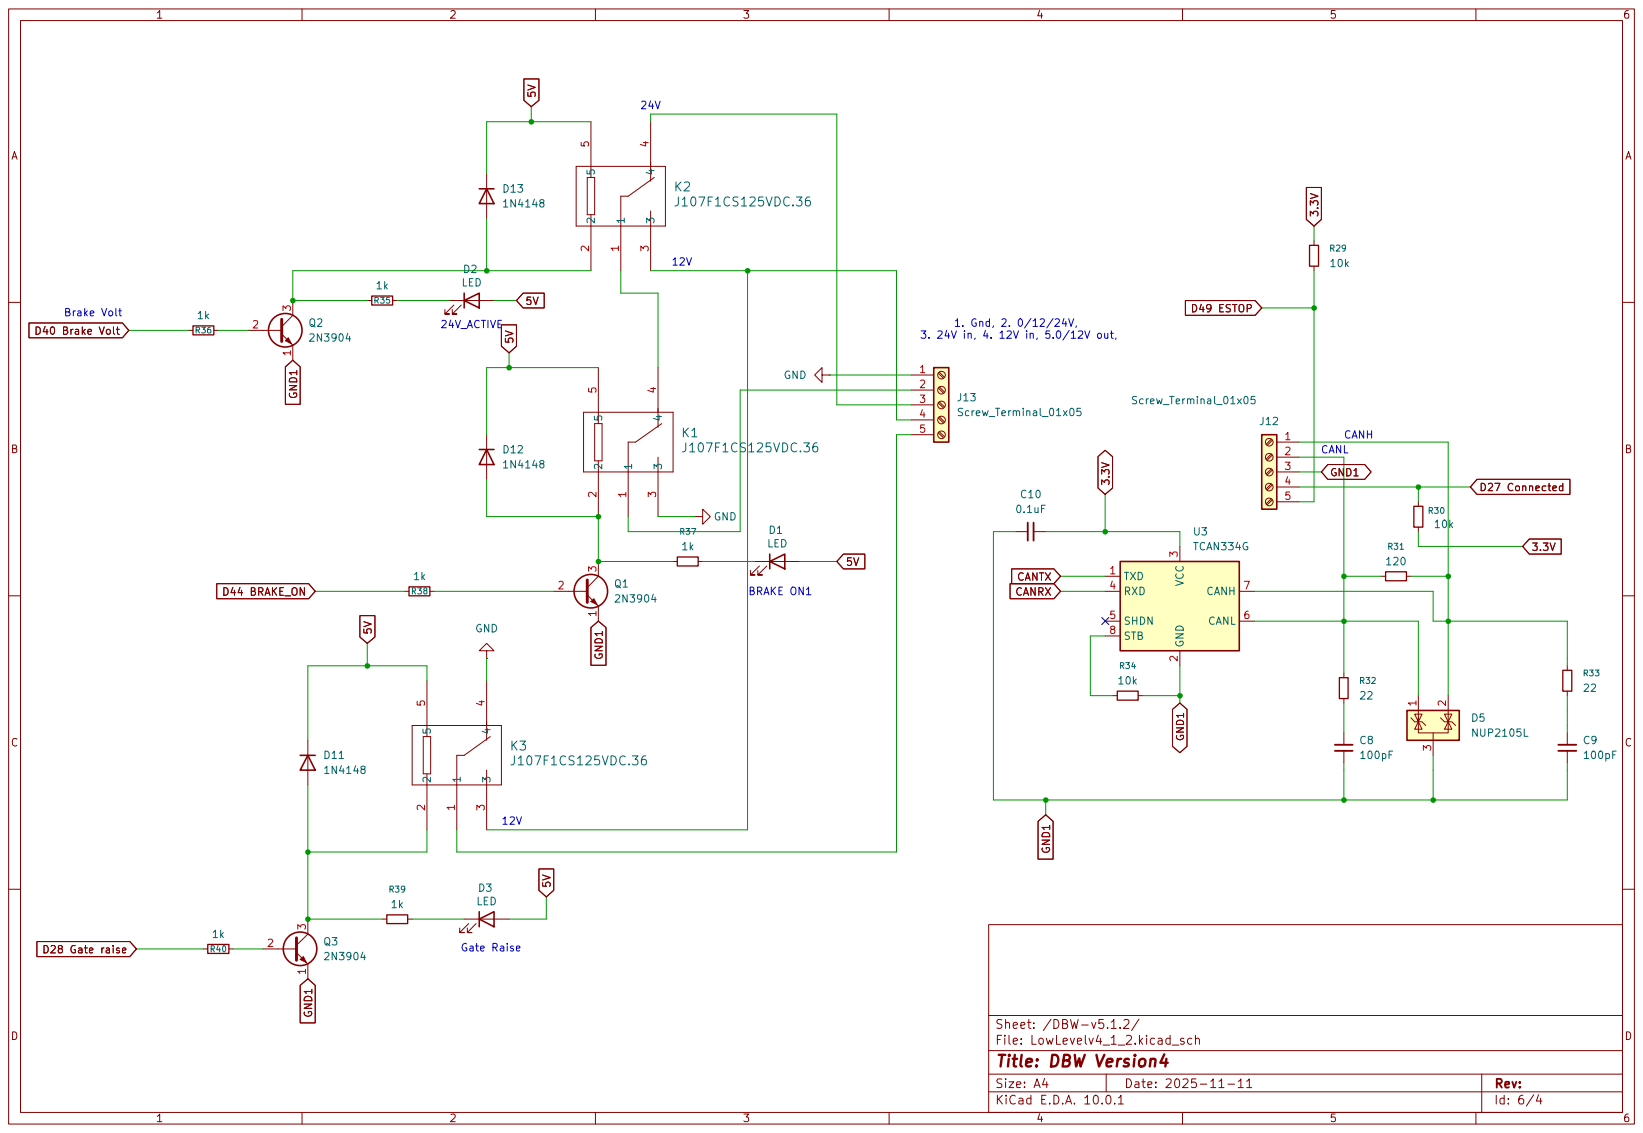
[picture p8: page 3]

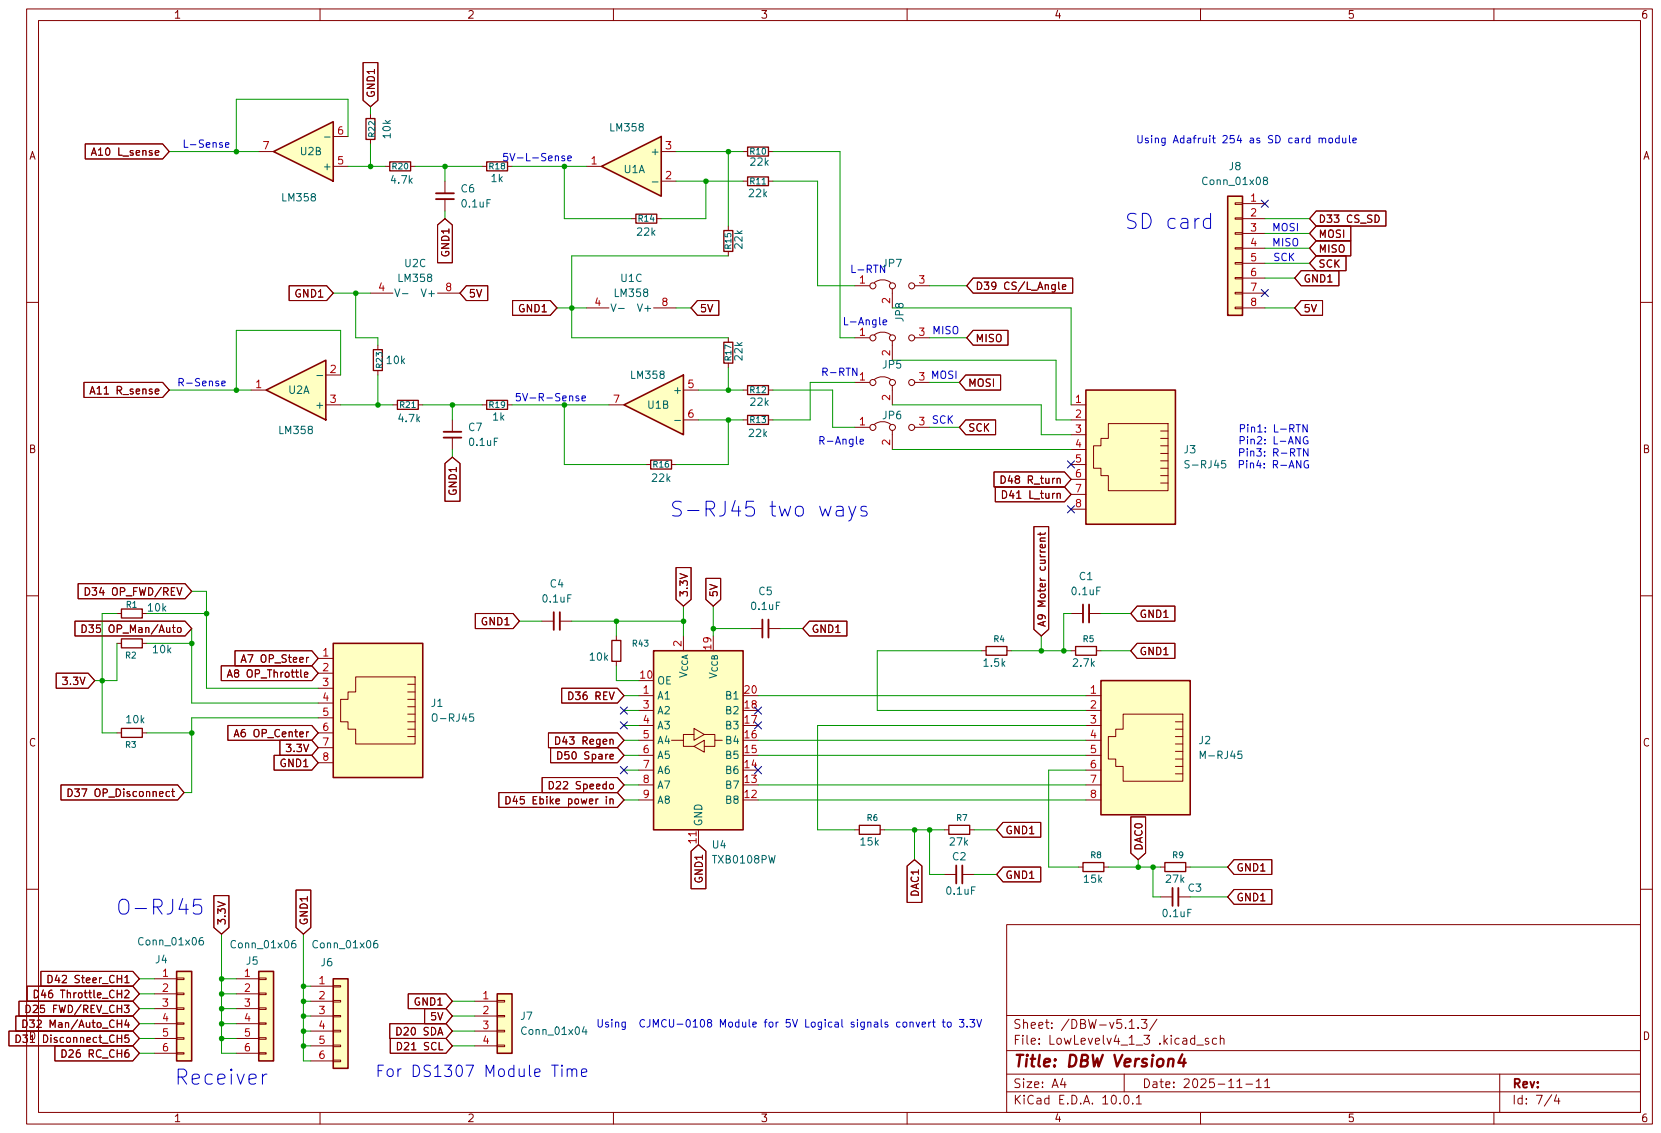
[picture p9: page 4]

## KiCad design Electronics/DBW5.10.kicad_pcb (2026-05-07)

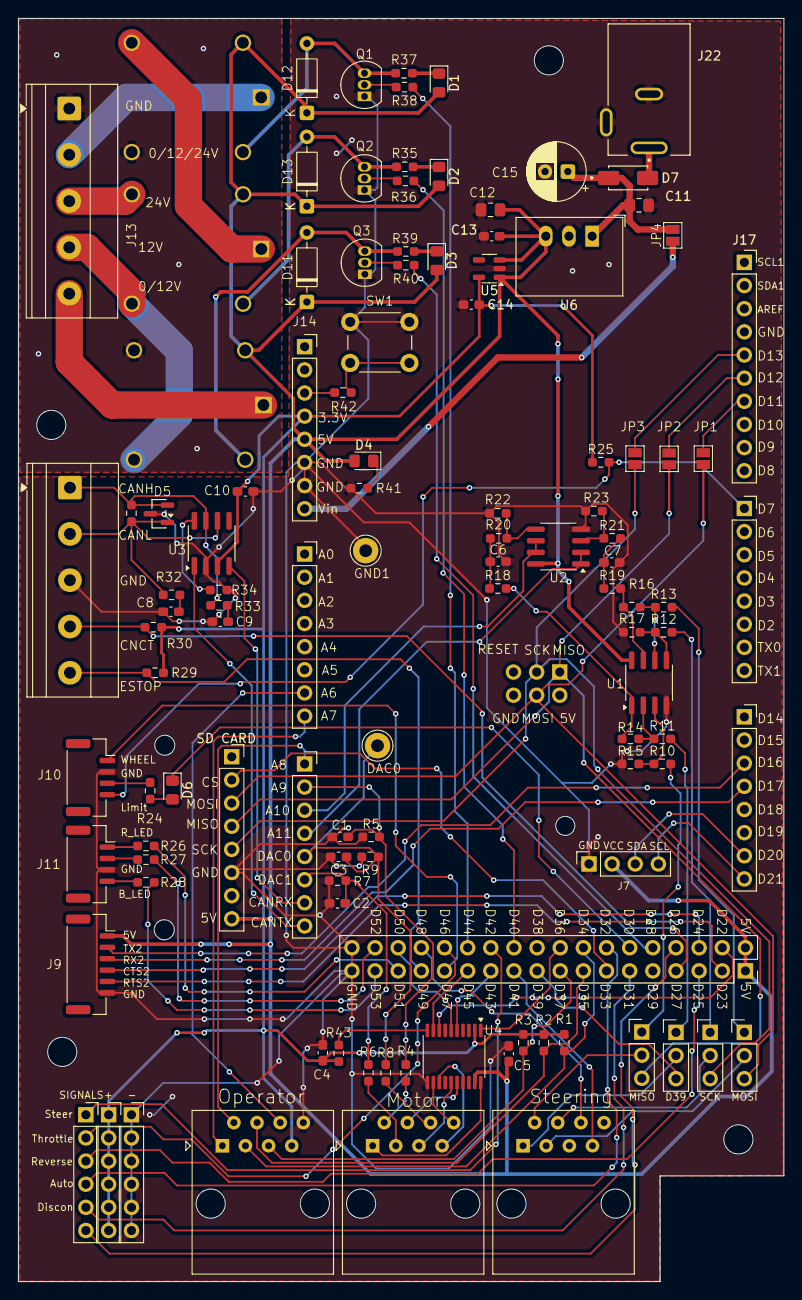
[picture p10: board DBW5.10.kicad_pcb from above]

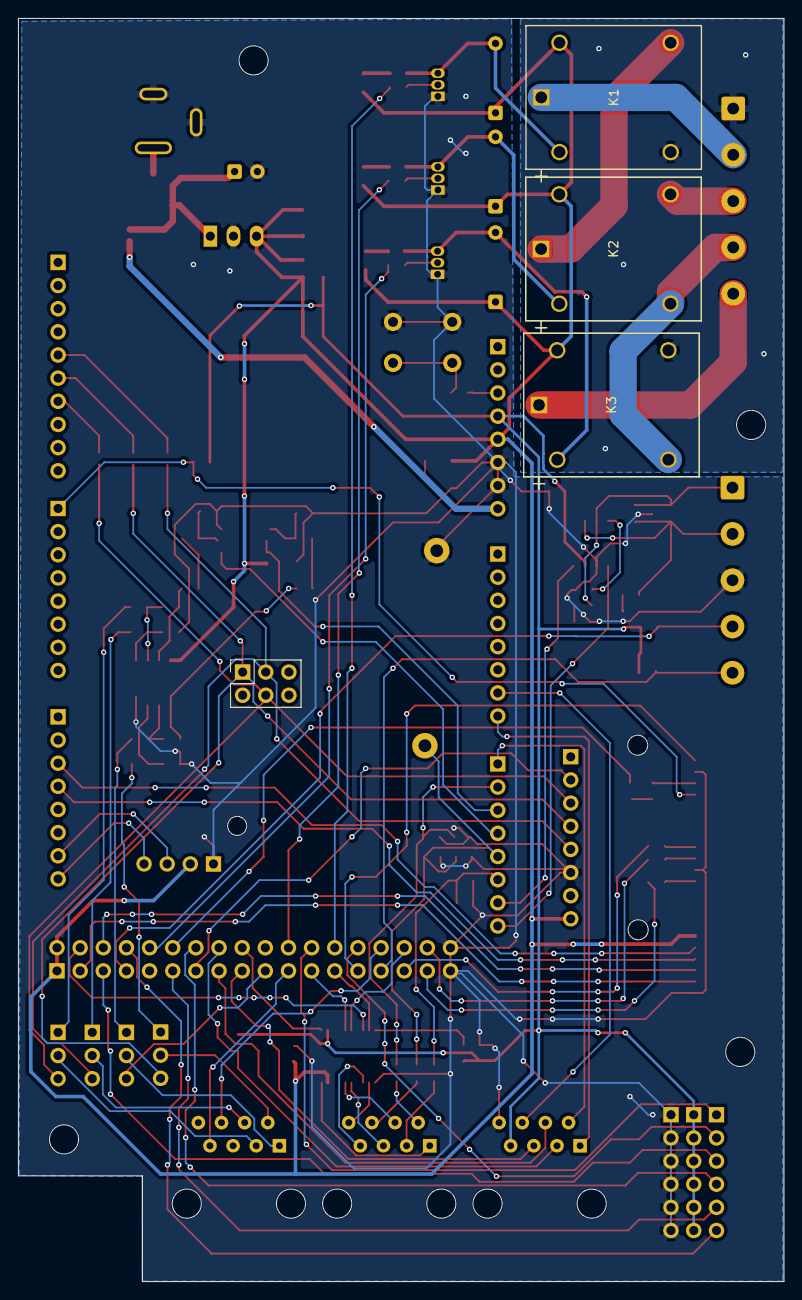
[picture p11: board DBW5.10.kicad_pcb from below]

Board: 2 copper layers, 84.0 x 138.6 mm, 113 parts (4 on the bottom side), 112 nets.

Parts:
C1, C2, C3, C4, C5, C10: 0.1uF; C_0603_1608Metric_Pad1.08x0.95mm_HandSolder
C6, C7: 100nF; C_0603_1608Metric_Pad1.08x0.95mm_HandSolder
C8, C9: 100pF; C_0603_1608Metric_Pad1.08x0.95mm_HandSolder
C11, C12: 10uF; C_0805_2012Metric_Pad1.18x1.45mm_HandSolder
C13, C14: 1uF; C_0603_1608Metric_Pad1.08x0.95mm_HandSolder
C15: 47uF; CP_Radial_D6.3mm_P2.50mm
D1, D2, D3: LED; LED_0805_2012Metric_Pad1.15x1.40mm_HandSolder
D4: LED_Power; LED_0805_2012Metric_Pad1.15x1.40mm_HandSolder
D5: NUP2105L; SOT-23
D6: LED_Debug; LED_0805_2012Metric_Pad1.15x1.40mm_HandSolder
D7: B140-13-F; DIOM4326X240N
D11, D12, D13: 1N4148; D_DO-35_SOD27_P7.62mm_Horizontal
DAC0: TestPoint; TestPoint_Loop_D2.60mm_Drill1.4mm_Beaded
GND1: TestPoint; TestPoint_Loop_D2.60mm_Drill1.4mm_Beaded
J1: O-RJ45; RJ45_Amphenol_54602-x08_Horizontal
J2: M-RJ45; RJ45_Amphenol_54602-x08_Horizontal
J3: S-RJ45; RJ45_Amphenol_54602-x08_Horizontal
J4, J5, J6: Conn_01x06; PinSocket_1x06_P2.54mm_Vertical
J7: Conn_01x04; PinSocket_1x04_P2.54mm_Vertical
J8, J14, J15, J16, J18, J19: Conn_01x08; PinSocket_1x08_P2.54mm_Vertical
J9: Conn_01x06; JST_GH_SM06B-GHS-TB_1x06-1MP_P1.25mm_Horizontal
J10, J11: Conn_01x04; JST_GH_SM04B-GHS-TB_1x04-1MP_P1.25mm_Horizontal
J12, J13: Screw_Terminal_01x05; TerminalBlock_Phoenix_MKDS-1,5-5-5.08_1x05_P5.08mm_Horizont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
J17: Conn_01x10; PinSocket_1x10_P2.54mm_Vertical
J20: Conn_02x18_Odd_Even; PinSocket_2x18_P2.54mm_Vertical
J21: Conn_02x03_Odd_Even; PinSocket_2x03_P2.54mm_Vertical
J22: 54-00129; TENSILITY_54-00129
JP1, JP2, JP3, JP4: Jumper_2_Open; SolderJumper-2_P1.3mm_Open_Pad1.0x1.5mm
JP5, JP6, JP7, JP8: Jumper_3_Bridged12; PinHeader_1x03_P2.54mm_Vertical
K1, K2, K3: J107F1CS125VDC.36; RELAY5_J107F-1C_CRS
Q1, Q2, Q3: 2N3904; TO-92_Inline
R1, R2, R3, R22, R23, R25, R29, R30, R34, R43: 10k; R_0603_1608Metric_Pad0.98x0.95mm_HandSolder
R4: 1.5k; R_0603_1608Metric_Pad0.98x0.95mm_HandSolder
R5: 2.7k; R_0603_1608Metric_Pad0.98x0.95mm_HandSolder
R6, R8: 15k; R_0603_1608Metric_Pad0.98x0.95mm_HandSolder
R7, R9: 27k; R_0603_1608Metric_Pad0.98x0.95mm_HandSolder
R10, R11, R12, R13, R14, R15, R16, R17: 22k; R_0603_1608Metric_Pad0.98x0.95mm_HandSolder
R18, R19, R35, R36, R37, R38, R39, R40, R41: 1k; R_0603_1608Metric_Pad0.98x0.95mm_HandSolder
R20, R21: 4.7k; R_0603_1608Metric_Pad0.98x0.95mm_HandSolder
R24: 1K; R_0603_1608Metric_Pad0.98x0.95mm_HandSolder
R26, R27, R28: 150; R_0603_1608Metric_Pad0.98x0.95mm_HandSolder
R31: 120; R_0603_1608Metric_Pad0.98x0.95mm_HandSolder
R32, R33: 22; R_0603_1608Metric_Pad0.98x0.95mm_HandSolder
R42: 100; R_0603_1608Metric_Pad0.98x0.95mm_HandSolder
SW1: SW_Push; SW_PUSH_6mm
U1, U2: LM358; SOIC-8_3.9x4.9mm_P1.27mm
U3: TCAN334G; SOIC-8_3.9x4.9mm_P1.27mm
U4: TXB0108PW; TSSOP-20_4.4x6.5mm_P0.65mm
U5: TLV75533PDBV; SOT-23-5
U6: R-78E5.0-1.0; Converter_DCDC_RECOM_R-78E-0.5_THT

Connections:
3.3V: C4.2, C10.2, C14.1, J1.7, J5.1, J5.2, J5.3, J5.4, J5.5, J5.6, J14.4, R1.1, R2.2, R3.2, R25.1, R29.2, R30.2, R43.1, U3.3 (VCC), U4.2 (V_{CCA}), U5.5 (OUT)
5V: C5.1, C12.1, C13.1, D1.2 (A), D2.2 (A), D3.2 (A), D4.2 (A), D11.1 (K), D12.1 (K), D13.1 (K), J7.2, J8.8, J9.1, J14.5, J20.1, J20.2, K1.5, K2.5, K3.5, U1.8 (V+), U2.8 (V+), U4.19 (V_{CCB}), U5.1 (IN), U5.3 (EN), U6.3 (OUT)
9V: C11.1, C15.1, D7.C, JP4.2 (B), U6.1 (IN)
A6 OP_Center: J1.6, J15.7
A7 OP_Steer: J1.1, J15.8
A8 OP_Throttle: J1.2, J16.1
A9 Moter current: C1.1, J16.2, R4.2, R5.1
A10 L_sense: J16.3, U2.6 (-), U2.7
A11 R_sense: J16.4, U2.1, U2.2 (-)
CANRX: J16.7, U3.4 (RXD)
CANTX: J16.8, U3.1 (TXD)
D7 Gate_limit: J10.4, J18.1, R25.2
D16 Tx2: J9.2, J19.3
D17 Rx2: J9.3, J19.4
D20 SDA: J7.3, J19.7
D21 SCL: J7.4, J19.8
D22 Speedo: J20.4, U4.8 (A7)
D23 RTS2: J9.5, J20.3
D24 CTS2: J9.4, J20.6
D25 FWD/REV_CH3: J4.3, J20.5
D26 RC_CH6: J4.6, J20.8
D27 Connected: J12.4, J20.7, R30.1
D28 Gate raise: J20.10, R40.2
D30 DEBUG_LED: D6.1 (K), J20.12
D31 Disconnect_CH5: J4.5, J20.11
D32 Man/Auto_CH4: J4.4, J20.14
D33 CS_SD: J8.2, J20.13
D34 OP_FWD/REV: J1.3, J20.16, R1.2
D35 OP_Man/Auto: J1.4, J20.15, R2.1
D36 REV: J20.18, U4.1 (A1)
D37 OP_Disconnect: J1.5, J20.17, R3.1
D39 CS/L_Angle: J20.19, JP7.3 (B)
D40 Brake Volt: J20.22, R36.2
D41 L_turn: J3.7, J20.21
D42 Steer_CH1: J4.1, J20.24
D43 Regen: J20.23, U4.5 (A4)
D44 BRAKE_ON: J20.26, R38.2
D45 Ebike power in: J20.25, U4.9 (A8)
D46 Throttle_CH2: J4.2, J20.28
D47 IRPT_WHEEL: J10.1, J20.27
D48 R_turn: J3.6, J20.30
D49 ESTOP: J12.5, J20.29, R29.1
D50 Spare: J20.32, U4.6 (A5)
D51 Red Light: J20.31, R26.2
D52 Green Light: J20.34, R27.2
D53 Blue Light: J20.33, R28.2
DAC0: C3.1, DAC0.1, J16.5, R8.2, R9.1
DAC1: C2.1, J16.6, R6.2, R7.1
GND: J13.1, K1.3, K3.4
GND1: C1.2, C2.2, C3.2, C4.1, C5.2, C6.1, C7.1, C8.1, C9.1, C10.1, C11.2, C12.2, C13.2, C14.2, C15.2, D5.3 (A), GND1.1, J1.8, J6.1, J6.2, J6.3, J6.4, J6.5, J6.6, J7.1, J8.6, J9.6, J10.2, J11.3, J12.3, J14.6, J14.7, J20.35, J20.36, J22.B, J22.C, Q1.1 (E), Q2.1 (E), Q3.1 (E), R5.2, R7.2, R9.2, R15.1, R17.2, R22.2, R23.2, R34.2, R41.1, SW1.1, U1.4 (V-), U2.4 (V-), U3.2 (GND), U4.11 (GND), U5.2 (GND), U6.2 (GND)
MISO: J8.4, J21.1, JP2.1 (A), JP8.3 (B)
MOSI: J8.3, J21.4, JP1.1 (A), JP5.3 (B)
unnamed: C6.2, R18.1, R20.2
unnamed: C7.2, R19.1, R21.2
unnamed: C8.2, R32.1
unnamed: C9.2, R33.1
unnamed: D1.1 (K), R37.1
unnamed: D2.1 (K), R35.1
unnamed: D3.1 (K), R39.1
unnamed: D4.1 (K), R41.2
unnamed: D6.2 (A), R24.2
unnamed: D7.A, J22.A
unnamed: D11.2 (A), K3.2, Q3.3 (C), R39.2
unnamed: D12.2 (A), K1.2, Q1.3 (C), R37.2
unnamed: D13.2 (A), K2.2, Q2.3 (C), R35.2
unnamed: J2.2, R4.1
unnamed: J2.3, R6.1
unnamed: J2.6, R8.1
unnamed: J10.3, R24.1
unnamed: J11.1, R26.1
unnamed: J11.2, R27.1
unnamed: J11.4, R28.1
unnamed: D5.2 (K), J12.1, R31.1, R33.2, U3.7 (CANH)
unnamed: D5.1 (K), J12.2, R31.2, R32.2, U3.6 (CANL)
unnamed: J13.2, K1.1
unnamed: J13.3, K2.4
unnamed: J13.4, K2.3, K3.3
unnamed: J13.5, K3.1
unnamed: J14.8, JP4.1 (A)
unnamed: J17.5, JP3.2 (B)
unnamed: J17.6, JP2.2 (B)
unnamed: J17.7, JP1.2 (B)
unnamed: JP5.1 (A), R13.2
unnamed: J3.3, JP5.2 (C)
unnamed: JP6.1 (A), R12.2
unnamed: J3.4, JP6.2 (C)
unnamed: JP7.1 (A), R11.2
unnamed: J3.1, JP7.2 (C)
unnamed: JP8.1 (A), R10.2
unnamed: J3.2, JP8.2 (C)
unnamed: K1.4, K2.1
unnamed: Q1.2 (B), R38.1
unnamed: Q2.2 (B), R36.1
unnamed: Q3.2 (B), R40.1
unnamed: R14.1, R18.2, U1.1
unnamed: R16.1, R19.2, U1.7
unnamed: R42.1, SW1.2
unnamed: R10.1, R15.2, U1.3 (+)
unnamed: R11.1, R14.2, U1.2 (-)
unnamed: R12.1, R17.1, U1.5 (+)
unnamed: R13.1, R16.2, U1.6 (-)
unnamed: R21.1, R23.1, U2.3 (+)
unnamed: R20.1, R22.1, U2.5 (+)
unnamed: R34.1, U3.8 (STB)
unnamed: J2.1, U4.20 (B1)
unnamed: J2.4, U4.16 (B4)
unnamed: J2.5, U4.15 (B5)
unnamed: J2.7, U4.13 (B7)
unnamed: J2.8, U4.12 (B8)
unnamed: R43.2, U4.10 (OE)
RESET: J14.3, R42.2
SCK: J8.5, J21.3, JP3.1 (A), JP6.3 (B)

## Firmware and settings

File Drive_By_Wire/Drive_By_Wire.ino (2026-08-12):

/* Drive_By_Wire
 *  Implement vehicle throttle, brakes and steering as commanded
 *  Report status over CAN bus
 *  Accept commands over CAN bus
 */
#include "DBW_Pins.h"
#include "Vehicle.h"
#include <Arduino.h>

#define baud 115200  // baudrate for debugging with a host PC over USB serial
Vehicle *myTrike;
Logger *Log;

void setup() {
  pinMode (RED_LED_PIN, OUTPUT);
  pinMode (GREEN_LED_PIN, OUTPUT);
  pinMode (BLUE_LED_PIN, OUTPUT);
  // Set status LED to white to show initializing
  digitalWrite(RED_LED_PIN,HIGH);
  digitalWrite(GREEN_LED_PIN,HIGH);
  digitalWrite(BLUE_LED_PIN,HIGH);
  // Always begin Serial, even on the Bridge where it is not cabled to a PC.
  // Logger's initRTC()/initSD()/openSD() print to Serial unconditionally, and
  // UARTClass::write() spin-locks forever once its 128-byte buffer fills if
  // begin() was never called — the TX interrupt that drains it is enabled by
  // begin(). That would hang setup() and loop() would never run.
  Serial.begin(baud);
#ifdef USE_NATIVE_USB
  SerialUSB.begin(baud);
  // Wait up to 500 ms for a serial monitor; proceed regardless so automated
  // tests are not blocked when no monitor is connected. 500 ms is enough
  // for a monitor that was open before reset; cold-boot without monitor
  // starts DBW in < 500 ms so it's ready before the first test assertion.
  { uint32_t t = millis(); while (!SerialUSB && (millis() - t) < 500); }
#endif
  myTrike = new Vehicle();
  Log = new Logger();
}

void loop() {
   //Timing code
  const uint32_t offsetTime = 7;  // logged delays are 107 ms or more.
  uint32_t endTime;
  uint32_t delayTime;
  uint32_t timeStart_ms = millis();
  endTime = timeStart_ms + LOOP_TIME_MS;
  // Clock overflow will not happen unless if the vehicle is running for more than 49 days.
  // The batteries won't last that long without recharging.
  // Don't worry about clock rollover.
 // if (end_time < timeStart_ms) {  // clock rollover}

  myTrike->updateRC();      // get new desired settings from RC
  myTrike->receiveCan();    // override desired settings if CAN active
  myTrike->update();        // set throttle, steering and brakes to implement desired settings
                        // update sends a CAN message with actual velocity
  Log->update();         // write key data to SD
  //Timing code
  delayTime = endTime - millis() - offsetTime;
   Log->EndLine(delayTime);     // Finalize SD line by giving utilization
  if (delayTime <= 0) delayTime = 0;
  if (delayTime >= LOOP_TIME_MS) delayTime = LOOP_TIME_MS;
  // Instead of plain delay(), spin-drain CAN so we don't miss Sensor Hub's
  // 0x350/0x100 frames while DBW's own Logger floods the bus with 0x701-0x70A.
  uint32_t spinUntil = millis() + delayTime;
  while (millis() < spinUntil) {
    myTrike->receiveCan();
  }

}

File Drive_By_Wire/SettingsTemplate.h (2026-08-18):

/*
 * Settings.h is meant to capture characteristics of a particular vehicle.
 * There shoould be no Settings.h file in the GitHub repository.
 * The file in the repository should be SettingsTemplate.h
 * Modify this example file to match your individual vehicle.
 * Do not check your local Settings.h into the repository.
 */

#pragma once
//#define VEHICLE_NAME "01 Orange Trike"
#define VEHICLE_NAME "02 Yellow Trike"
#define RELAYInversion true
/*=======================================================================
Minimum and maximum values to send to the motor
Minimum and maximum speed allowed
*/

// max speed
#define MAX_SPEED_KmPh 20
#define KmPh_cmPs  (100000 / 3600) 
//at 20KMPH this is roughly 5,555 mm/s
#define MAX_SPEED_cmPs (MAX_SPEED_KmPh * KmPh_cmPs)
#define MAX_SPEED_mmPs (MAX_SPEED_cmPs * 10)

// small min speed is interpreted as stopped
//set as 1% of the maximum speed -> 0.2 KmPh
#define MIN_SPEED_cmPs  (0.01 * MAX_SPEED_cmPs)

/*=========================================================================
Settings for the Steering */
#define STR_PWM     0
#define STR_HBRIDGE 1
#define STR_MOTOR_CONTROL 2
// Yellow trike uses pulse width steering servo
// #define STEER_METHOD STR_PWM
// Orange trike uses motor control shield with feedback from angle sensor
#define STEER_METHOD STR_MOTOR_CONTROL
/* Minimum/Maximum and center turning signals
*/
// Which sensors are enabled: left or right steering column; analog, SPI or CAN
#define R_ANALOG 0x01
#define R_SPI    0x02
#define R_CAN    0x04
#define L_ANALOG 0x10
#define L_SPI    0x20
#define L_CAN    0x40
// combine all present senor bits with |
#define ANGLE_CONFIG L_ANALOG 
// Minimum turn in Degrees*10;  -240 = Left 24 degrees
#define MIN_LEFT_DEGx10 -240
// Maximum turn in Degrees*10; 250 = Right 25 degrees
#define MAX_RIGHT_DEGx10 250
// if using pulse width control for steering, the minimum pulse in microseconds
#define MIN_LEFT_US 1000
// maximum steering servo pulse width in us
#define MAX_RIGHT_US 1850
// Steering pulse widths in us for straight
#define STRAIGHT_US 1500
// For motor controller board, time in ms to move motor
// negative = left; positive right
#define LEFT_ST_MS    -900
#define RIGHT_ST_MS     900


/* There are wheel angle sensors on the left and right steering columns
   Each returns an analog voltage between 0 and 5 volts.
   After the signal passes through ADC it is a value from 0 to 1023.
   Idealy we would line up the sensors so that 511 is straight ahead.
   It is not practical to get ideal alignment.
   Move the wheels to extreme left to get the read value at MIN_TURN.
   Move the wheels to extreme right to get the read value at MAX_TURN.
   These settings will vary significantly from vehicle to vehicle.
*/
/*
// These values have worked for the Carla simulator
#define Left_Read_at_MIN_TURN 532
#define Left_Read_at_MAX_TURN 206
#define Right_Read_at_MIN_TURN 106
#define Right_Read_at_MAX_TURN 532
// These are some typical values for orange trike
#define Left_Read_at_MIN_TURN 485
#define Left_Read_at_MAX_TURN 313
#define Right_Read_at_MIN_TURN 725
#define Right_Read_at_MAX_TURN 785
*/
 // Min_turn =Hard right
#define Right_Read_at_MIN_TURN 673
// Max_turn= Hard left
#define Right_Read_at_MAX_TURN 786 
// right side of drive
#define Right_Straight_Read    731 
 // Yellow Trike wheel angle sensor in ms
// wheel angle sensor had issues only using right sensor values
// Min_turn =Hard right
#define Left_Read_at_MIN_TURN 779 
// Max_turn= Hard left
#define Left_Read_at_MAX_TURN 639 
// left side of drive
#define Left_Straight_Read    722 

/*======================================================================
Vehicle Data
Wheel Diameter, Turn Radius
*/

#define WHEEL_DIAMETER_MM 495.3
//derived settings
#define WHEEL_CIRCUM_MM (WHEEL_DIAMETER_MM * PI)

/*=======================================================================
PID tuning for steering and throttle
*/

#define PID_SAMPLE_TIME 100

// Motor PID
const float proportional_throttle = .0175;
const float integral_throttle = .2;
const float derivative_throttle = .00001;

// Steering PID
const float proportional_steering = .0175;
const float integral_steering = .5;
const float derivative_steering = .00001;
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

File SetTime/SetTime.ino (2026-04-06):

/*
 * SetTime.ino
 *
 * Utility sketch for setting the DS1307 real-time clock (RTC) on the
 * Drive-By-Wire board. Upload this sketch, open Serial Monitor at 9600
 * baud, and type the current time in the format shown below. The RTC
 * will retain the time after the sketch is replaced with the main firmware.
 *
 * Usage:
 *   Enter time as: YYYY-MM-DD HH:MM:SS
 *   Example:       2026-04-02 18:45:30
 *
 * Hardware:
 *   - DS1307 RTC connected via I2C (SDA/SCL)
 *   - Arduino Due (or compatible board with Wire support)
 *
 * Dependencies:
 *   - DS1307RTC  (https://github.com/PaulStoffregen/DS1307RTC)
 *   - TimeLib    (https://github.com/PaulStoffregen/Time)
 *   - Wire       (built-in)
 */

#include <Wire.h>
#include <DS1307RTC.h>
#include <TimeLib.h>

String inputLine = "";

void setup() {
  Serial.begin(9600);
  while (!Serial) {
    ; // wait for Serial on boards that need it
  }

  Wire.begin();

  Serial.println("SetTime sketch started.");
  Serial.println("Enter time in this format:");
  Serial.println("YYYY-MM-DD HH:MM:SS");
  Serial.println("Example: 2026-04-02 18:45:30");
  Serial.println();
}

void loop() {
  while (Serial.available() > 0) {
    char c = Serial.read();

    if (c == '\r') {
      // ignore carriage return
      continue;
    }

    if (c == '\n') {
      if (inputLine.length() > 0) {
        processInput(inputLine);
        inputLine = "";
      }
    } else {
      inputLine += c;
    }
  }

  printRTCTime();
  delay(1000);
}

void processInput(String s) {
  int year, month, day, hour, minute, second;

  int matched = sscanf(
    s.c_str(),
    "%d-%d-%d %d:%d:%d",
    &year, &month, &day,
    &hour, &minute, &second
  );

  if (matched != 6) {
    Serial.println("Invalid format.");
    Serial.println("Use: YYYY-MM-DD HH:MM:SS");
    return;
  }

  tmElements_t tm;
  tm.Year = CalendarYrToTm(year);
  tm.Month = month;
  tm.Day = day;
  tm.Hour = hour;
  tm.Minute = minute;
  tm.Second = second;

  bool ok = RTC.write(tm);

  if (ok) {
    Serial.println("RTC updated successfully.");
  } else {
    Serial.println("RTC write failed.");
  }
}

void printRTCTime() {
  tmElements_t tm;

  if (RTC.read(tm)) {
    char buf[25];
    sprintf(
      buf,
      "%02d:%02d:%02d  %02d/%02d/%04d",
      tm.Hour,
      tm.Minute,
      tm.Second,
      tm.Month,
      tm.Day,
      tmYearToCalendar(tm.Year)
    );
    Serial.println(buf);
  } else {
    Serial.println("RTC read error!");
  }
}

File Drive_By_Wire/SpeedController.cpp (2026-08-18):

#include <Arduino.h>
#include "DBW_Pins.h"
#include "SpeedController.h"

volatile uint32_t SpeedController::tickTime_ms[2];

SpeedController::SpeedController()
  : speedPID(&speedCyclometer_cmPs, &PIDThrottle, &desiredSpeed_cmPs, proportional_throttle, integral_throttle, derivative_throttle, DIRECT) 
{
   // Initialize Pins
  pinMode(BRAKE_ON_PIN, OUTPUT);
  pinMode(BRAKE_VOLT_PIN, OUTPUT);
  // Brakes are released as a default setting
  state = BR_OFF;
  ReleaseBrakes(); 
  brake_change_ms = 0;  // only used when brakes on
  
  currentThrottle = 0;
  speedPID.SetControlLimits(MIN_PID_TH, MAX_PID_TH);
  speedPID.SetSampleTime(PID_SAMPLE_TIME);
  speedPID.SetMode(AUTOMATIC);
  calcTime_ms[0] = 0;
  calcTime_ms[1] = 0;
  prevSpeed_cmPs = 0;

  attachInterrupt(IRPT_WHEEL, tick, RISING);
  if (DEBUG)
    Serial.println("Speed Setup Complete");
}

SpeedController::~SpeedController() {
}

// Interrupt service routine
void SpeedController::tick() {
  uint32_t tick = millis();
  noInterrupts();
  if ((tick - tickTime_ms[0]) > MIN_TICK_TIME_ms) {
    tickTime_ms[1] = tickTime_ms[0];
    tickTime_ms[0] = tick;
  }
  interrupts();
}

/**
 * receives requested speed from Vehicle requested from High Level board
 * attempts to adjust speed either through PIDS or standard engageThrottle() 
 * based on the PIDs being on or off in Settings
 * param dSpeed desired speed in mm/s
 */
int32_t SpeedController::update(int32_t dSpeed, DriveMode mode) {
  if (state == BR_HI_VOLTS && millis() > brake_change_ms)
  {
    digitalWrite(BRAKE_VOLT_PIN, OFF_BR);   // Use 12V activation
    state = BR_LO_VOLTS;
  }

  // If Nav (or the operator path) commands zero speed, bypass the PID and
  // brake hard. The PID's integral accumulates a positive bias during the
  // cruise phase; if we keep running PID(0) afterward, the integral keeps
  // DAC0 above zero and the ACCEL branch in ThrottlePID() releases the
  // brakes — so the simulator keeps reading "throttle on" and the trike
  // never actually stops. Same wind-up condition that would occur on the
  // real trike after a long cruise.
  if (dSpeed <= 0) {
    Stop();
    computeSpeed();
    return 0;
  }

  // Kelley e-bike controller is capbale of reverse, but trike freewheel will prevent it.
  // Need a fixed sprocket to implement reverse
  // if (mode == REVERSE_MODE) {
  //   dSpeed = constrain(dSpeed, 0, 150);  // prevent negatives
  //   dSpeed = map(dSpeed, 0, 150, 150, 0);  // invert DAC for reverse, or just limit
  // }

  ThrottlePID(dSpeed);
  computeSpeed();

  if (DEBUG) {
    Serial.println("cm Speed: " + String(speedCyclometer_cmPs));
    Serial.print("PWM speed: ");
    Serial.println(currentThrottle);
  }
  return currentThrottle;
}

void SpeedController::ThrottlePID(int32_t desiredValue) {
  // speedPID(&speedCyclometer_cmPs, &PIDThrottle, &desiredSpeed_cmPs)
  // BUGFIX: write the param into the setpoint that PID actually reads through
  // its pointer. Without this line PID always sees setpoint=0 and never
  // throttles up regardless of what Nav commands.
    desiredSpeed_cmPs = desiredValue;
    speedPID.Compute();
    if (PIDThrottle < PID_BRAKE)
    {  // Apply brakes
      Stop();
    }
    else if (PIDThrottle < PID_COAST)
    {  // coast
      currentThrottle = 0;
      ReleaseBrakes();
    }
    else
    {  // accelerate
      // The MAP arguments were the wrong way round. MIN_THROTTLE/MAX_THROTTLE
      // are DAC counts (see the calibration table in SpeedController.h: "1.187 V:
      // nothing 75"), not a PID output range, while PIDThrottle spans
      // MIN_PID_TH..MAX_PID_TH from SetControlLimits(). Mapping 75..175 onto
      // 10..255 gave currentThrottle a -149..451 range, and analogWrite() only
      // accepts 0..255 - out-of-range values wrapped in the 12-bit DACC register
      // instead of clamping, so a larger number could produce less throttle.
      // Map the PID's own output range onto the calibrated DAC band instead.
      currentThrottle = MAP(PIDThrottle,PID_COAST,MAX_PID_TH,MIN_THROTTLE,MAX_THROTTLE);
      ReleaseBrakes();
    }
   analogWrite(DAC0,currentThrottle);
}

int32_t SpeedController::extrapolateSpeed() {
  int32_t y;
  int32_t t = millis();
  //slope calculation
  y = (speedCyclometer_cmPs - prevSpeed_cmPs) / (calcTime_ms[0] - calcTime_ms[1]);
  // * change in time
  y *= (t - calcTime_ms[0]);
  // + current speed
  y += speedCyclometer_cmPs;

  if (y < 0)
    y = 0;
  return y;
}
/*
Uses previous two speeds to extrapolate the current speed
Used to determine when we have stopped
*/
void SpeedController::computeSpeed() {
  uint32_t tempTick[2];
  noInterrupts();
  tempTick[0] = tickTime_ms[0];
  tempTick[1] = tickTime_ms[1];
  interrupts();
  if (tempTick[1] == 0)
    speedCyclometer_cmPs = 0;
  else if (calcTime_ms[0] == 0) {
    speedCyclometer_cmPs = WHEEL_CIRCUM_MM * (100.0 / (tempTick[0] - tempTick[1]));
    prevSpeed_cmPs = speedCyclometer_cmPs;
    calcTime_ms[1] = tempTick[1];
    calcTime_ms[0] = tempTick[0];
  } else {
    if (calcTime_ms[1] == tempTick[1]) {
      uint32_t timeDiff = millis() - calcTime_ms[0];
      if (timeDiff > MAX_TICK_TIME_ms) {
        speedCyclometer_cmPs = 0;
        if (timeDiff > (2 * MAX_TICK_TIME_ms)) {
          prevSpeed_cmPs = 0;
          noInterrupts();
          tickTime_ms[1] = 0;
          interrupts();
        }
      } else if (prevSpeed_cmPs > speedCyclometer_cmPs) {
        speedCyclometer_cmPs = extrapolateSpeed();
      }
    } else {
      calcTime_ms[1] = calcTime_ms[0];
      calcTime_ms[0] = tempTick[0];
      prevSpeed_cmPs = speedCyclometer_cmPs;
      speedCyclometer_cmPs = WHEEL_CIRCUM_MM * (100.0 / (tempTick[0] - tempTick[1]));
    }
  }
}
void SpeedController::ReleaseBrakes() {
  // Release the brakes, state becomes BR_OFF
  // physically DISENGAGE the brakes
  digitalWrite(BRAKE_ON_PIN, OFF_BR); 
  digitalWrite(BRAKE_VOLT_PIN, OFF_BR); 
  state = BR_OFF;
}

/* Expected behavior:
    * This function should physically ENGAGE the brakes (apply 24V initially).
    * Based on observation, sending LOW to the pins physically ENGAGES.
    * Both LEDs come on for Relays 2 and 3
    * Relay 2 connects NO (solenoids) to COM (ground)
    * Relay 3 connects COM (other end of solenoids) to NC (36V)
    */
void SpeedController::Stop() {
 // set the throttle signal to zero
  analogWrite(DAC0, 0);
  currentThrottle = 0;
  if (state == BR_OFF)
  {  // first time to apply brakes
    digitalWrite(BRAKE_VOLT_PIN, ON_BR);   // Use 24V activation
    digitalWrite(BRAKE_ON_PIN, ON_BR);
    brake_change_ms = millis() + MAXHI_MS; 
    state = BR_HI_VOLTS;  
  }
  else if (state == BR_HI_VOLTS && millis() > brake_change_ms)
  {
    digitalWrite(BRAKE_VOLT_PIN, OFF_BR);   // Use 12V activation  
    state = BR_LO_VOLTS;
  }
}
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

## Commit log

2025-11-20 Rewrite of version 4 drive by wire
    Numerous changes
2026-01-07 Add files via upload
    New diagram and more information on steering connector
2026-01-07 Pins and connectors for DBW board
    [DBW5_Pin Mapping.csv]
2026-04-08 Fix RC control and logger bugs found during hardware testing
    [DBW_Pins.h, Logger.cpp, RC_Controller.cpp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]
2026-04-10 corrected settings for op_estop and enabled
    [RC_Controller.cpp]
2026-04-16 Fix Operator Joystick Control Bugs
    This PR fixes several bugs found during bench testing with the operator
    joystick on the Yellow Trike (Vehicle 02), with no vehicle connected.
    The joystick inputs were not being processed correctly in OPERATOR_MODE
    and the data log was showing garbage values.
    Bug 1 - Joystick throttle and steering had no effect:
    In OPERATOR_MODE the system ignored all joystick inputs. The code was
    only reading joystick values in MANUAL_MODE. Fixed by adding joystick
    input handling to OPERATOR_MODE in Vehicle.cpp.
    Verified in log: desired_speed_ms and desired_angle_DegX10 now update
    correctly when the joystick is moved.
    Bug 2 - Forward/Reverse switch had no effect:
    Flipping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
    [Logger.cpp, RC_Controller.cpp, Vehicle.cpp]
2026-04-21 Fix Bridge board compatibility: CAN receive, serial logging, USB port
    - receiveCan(): handle 0x100 (speed/brake) and 0x350 (angle) separately;
    set canActive=true on receipt; watchFor() calls moved to constructor
    - update(): skip RC overwrite of desired values when canActive is set
    - RC_Controller: INITIALIZING falls through to AUTO_RC when no RC/operator
    - Logger: disable RTC init via HAS_RTC define (enabled by default);
    guard first_time Serial debug block with #ifndef USE_NATIVE_USB
    - DBW_Pins.h: remove hardcoded serialLOG; define it in Settings.h
    - Drive_By_Wire.ino: make SerialUSB init conditional on USE_NATIVE_USB;
    call receiveCan() in main loop
    - SettingsTemplate.h: add serialLOG,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
    [DBW_Pins.h, Drive_By_Wire.ino, Logger.cpp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]
2026-04-22 Adopt new Elcano CAN protocol for HiDrive/HiStatus
    Swap 0x100 and 0x350 to match the updated wiki protocol
    (elcanoproject.org/wiki/Communication): 0x350 HiDrive now carries
    speed/brake/angle, and 0x100 HiStatus carries a status-bit byte
    (0x80 e-stop, 0x40 autonomous, 0x04 reverse). Emit 0x200 LowStatus
    mirroring DBW's current mode so the Nav board can observe it. Add
    0x250/0x251 and 0x4C0 IDs to Can_Protocol.h for completeness.
    Verified on the bench with the SensorHub CanTest sketch: all ten
    scripted frames decoded correctly on DBW.
    [Vehicle.cpp]
2026-04-25 Fix RC channel ordering bug - uncomment channel swap in getMappedValue
    CHANGES: 1) Removed the early return statement on line 206 that was preventing the channel swap code from executing. 2) Uncommented lines 207-210 to enable the channel index swap. The RC_Controller was returning channels in wrong order (4,5,6,1,2,3 instead of 1,2,3,4,5,6). This caused log file to show steering on CH4 and throttle on CH5 instead of the correct channels.
    [RC_Controller.cpp]
2026-05-16 Update DBW for new CAN protocol and always-on CAN log emit
    - 0x350 receive: read brake as uint8 byte 2 and buffer the new mode byte,
    matching the current wiki spec.
    - Logger CAN emit: always run every loop tick (was a fallback only when
    SD failed), so any bus listener (Sensor Hub, future Jetson) can record
    the log stream. SD and serial logging remain as optional independent
    sinks.
    - Use fixed wiki IDs 0x701-0x70A instead of the auto-incrementing
    CANlogID scheme that overflowed each frame ID into the next.
    - Add CANLogOp (0x703) and CANLogAuto (0x704) emitters per the recent
    wiki additions. Buffer the last Nav-sent values in Vehicle for the
    Log_auto frame.
    - Fix EndLine finalize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
    [Logger.cpp, Vehicle.cpp]
2026-06-05 Map L_TURN/R_TURN to bridge wiring (D26/D28); disable CH6 collision
    DBW now drives the steering direction signals on the pins that are
    physically wired through to Router on the Bridge board (per Minhee):
    LEFT_TURN_PIN = D26 -> Router D4
    RIGHT_TURN_PIN = D28 -> Router D2
    Pin 26 is shared with CH6_PIN in DBW_Pins.h. Since RC channel 6 is
    reserved/unused on this trike, disable CH6's pinMode(INPUT) and the
    RISING attachInterrupt in RC_Controller's constructor so that
    SteeringController is the sole owner of pin 26 as an OUTPUT. The ISR
    function definitions are retained but never wired up.
    Also:
    - BRAKE_ON_PIN restored to D44 (had been migrated through a few pins
    during the steering-enco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
    [DBW_Pins.h, RC_Controller.cpp]
2026-06-05 Closed-loop steering against CAN-supplied wheel-angle feedback
    Replace the servo-pulse / motor-controller steering path with a
    two-wire digital direction scheme matching the bridge wiring. Each
    loop, SteeringPID asserts at most one of LEFT_TURN / RIGHT_TURN
    based on the sign of the error against the measured wheel angle:
    Nav -> 0x350 desired_angle -> DBW SteeringPID:
    err = desired - measured
    err > +deadband -> RIGHT_TURN HIGH, LEFT_TURN LOW
    err < -deadband -> LEFT_TURN HIGH, RIGHT_TURN LOW
    |err| <= deadband -> both LOW (hold)
    The measured wheel angle is supplied through Vehicle::update(). On
    the simulator, Router publishes its simulated angle_tenths on a new
    CAN frame: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
    [Drive_By_Wire.ino, SteeringController.cpp, Vehicle.cpp]
2026-06-05 Bypass throttle PID when desired speed is zero
    When Nav (or any other commander) requests speed=0, call Stop()
    directly instead of running ThrottlePID(0). The PID accumulates a
    positive integral during cruise; running PID(0) afterward keeps
    PIDThrottle above PID_COAST, the ACCEL branch fires and releases
    the brakes, and DAC0 stays above zero. In the simulator this means
    Router keeps reading "throttle on" and the trike never actually
    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
2026-06-06 Simplify open-loop steering fallback to fixed-step
    Replace the time-rate slew (200 degX10/sec scaled by dt_ms) in the
    haveMeasured==false branch of SteeringController::update() with a fixed
    +/-20 degX10 step per loop, matching Router's ANGLE_CHANGE_TENTHS
    directly. Removes the millis() read, the dt math, and the
    lastUpdate_ms member.
    The fallback only runs in degraded environments (sim without 0x430
    publisher, or real trike with absent analog feedback). In the normal
    closed-loop path, steerAngle_DegX10 is overwritten from
    measured_angle_DegX10 and this code does not execute.
    Verified the 4-WP simulator mission still completes cleanly.
    [SteeringController.cpp]
2026-07-12 Fix DBW control-loop freeze when USB monitor is closed
    Guard all SerialUSB writes behind a connected-host check so the Due's
    native USB flush()/print() can't block the control loop when no monitor
    drains the TX buffer. Previously steering/0x400 froze unless a serial
    monitor was open.
    - Drive_By_Wire.ino: bounded 500 ms startup wait instead of blocking forever
    - Logger.cpp update()/EndLine(): skip serial CSV + flush() when !SerialUSB
    - SteeringController.cpp / Vehicle.cpp: gate throttled debug prints on SerialUSB
    [Drive_By_Wire.ino, Logger.cpp, SteeringController.cpp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]
2026-07-13 DBW: brake-over-throttle safety, wider steering deadband, non-blocking USB logging
    - Vehicle.cpp: force stop when a brake is commanded so brake overrides throttle (previously ignored when speed>0, letting the trike keep driving with brake on).
    - SteeringController.cpp: widen DEADBAND_DegX10 5->10 (half the 20-tenth slew step) to stop the +/-10 center hunting limit-cycle; USB debug prints gated on availableForWrite.
    - Logger.cpp: gate SerialUSB writes on availableForWrite and drop flush() to prevent the 100ms control loop freezing when the USB buffer is not drained.
    [Logger.cpp, SteeringController.cpp, Vehicle.cpp]
2026-07-22 Added steer method for motor control shield
2026-08-04 DBW: fix logging sink selection, SD row commit, and RC channel mapping
    Addresses the DBW software items from the 2026-08-03 status email.
    Logging
    - Logger: pick the CSV sink by TYPE at compile time instead of comparing
    the objects. `serialLOG == logfile` invoked operator bool() on both
    sides; for SerialUSB that reports "is a USB host attached", false at
    boot, so the SD branch was selected by mistake and logMethod fell to 2,
    silencing the CSV entirely.
    - Route rows through a Print* sink so an SD failure falls back to a
    serial port instead of writing nothing anywhere ("ensure log files are
    always written").
    - Restore the per-row flush dropped in e2e168f. That commit removed the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
    [DBW_Pins.h, Drive_By_Wire.ino, Logger.cpp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]
2026-08-08 DBW: correct throttle speed units, operator mode override, log filename
    Follow-up to the previous commit, from bench testing on the DBW v5 board
    and the CARLA Bridge.
    Control
    - RC_Controller: map the throttle to MAX_SPEED_cmPs, not MAX_SPEED_mmPs.
    Both mapValues() and opUpdate() feed desired_speed_cmPs directly, so the
    mm/s scale asked for ten times the configured top speed — full throttle
    commanded ~194 km/h against a MAX_SPEED_KmPh of 20. Confirmed on
    hardware: full stick now yields 529 cm/s.
    - RC_Controller: let an enabled operator box take the mode from any state.
    op_enabled was only consulted from INITIALIZING, OPERATOR_MODE and
    AUTO_OP, so with an RC connected and CH4 ce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
    [Logger.cpp, RC_Controller.cpp, SpeedController.h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]
2026-08-11 Reversed pin assignments for RC
    [DBW5_Pin Mapping.csv]
2026-08-12 DBW: throttle scaling, mode-machine exits, operator deadbands, request logging
    Throttle
    - SpeedController: the MAP() arguments were reversed. MIN_THROTTLE/MAX_THROTTLE
    are DAC counts (see the calibration table: "1.187 V: nothing 75"), not a PID
    output range, so mapping 75..175 onto 10..255 gave currentThrottle a -149..451
    span. analogWrite() only accepts 0..255 and the Arduino SAM core does not
    clamp, so out-of-range values wrapped in the 12-bit DACC register instead -
    a larger number could produce less throttle. Now maps the PID's own output
    range onto the calibrated DAC band, giving a monotonic 75..175.
    RC input
    - MIN/MAX_RC_PULSE widened to 850..2200. The old 970..2030 window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
    [DBW_Pins.h, Logger.cpp, RC_Controller.cpp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]
2026-08-12 Corrected pin mappings for RC
    [DBW5_Pin Mapping.csv]
2026-08-18 Option for actuator tests
    On startup, if RC Reverse has been pressed, code will move steering, brakes and throttle. Code uses delays instead of the 100 ms steps of the rest of the code. Be prepared for the trike to move when testing - put it on a roller or hold up back wheel. Also updated steering to start using the three methods. More work is needed. Steer may be better without PID.
    [DBW_Pins.h, Logger.cpp, RC_Controller.cpp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]
2026-11-03 Use split OP_STEER/OP_THROTTLE deadbands in RC_Controller
    SettingsTemplate.h replaced OP_MIDLO/OP_MIDHI with separate steering and
    throttle deadbands, but opUpdate() still used the old names, so the sketch
    did not build from the template.
2026-11-03 Add pulse-width servo steering (STR_PWM)
    Fills in the STR_PWM stubs in SteeringController:
    - constructor attaches the servo on STEER_PULSE_PIN and centers it at
    STRAIGHT_US
    - SteeringPID() converts the desired angle to a pulse width, interpolating
    left and right separately from MIN_LEFT_US/STRAIGHT_US/MAX_RIGHT_US and
    MIN_LEFT_DEGx10/MAX_RIGHT_DEGx10, clamped to those limits
    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
2026-11-12 Schematics added
    The main KiCAD project has lost the link to the schematics. The zip file contains the three sheets of as-built schematics as Low_Level4_1_x.kicad.sch
